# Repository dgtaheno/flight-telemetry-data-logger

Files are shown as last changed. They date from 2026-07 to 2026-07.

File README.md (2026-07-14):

# 🚀 Flight Telemetry & Data Logger

> ESP32-based flight computer featuring GPS telemetry, barometric altitude measurement, runtime diagnostics, health monitoring and fault-tolerant flight data logging.

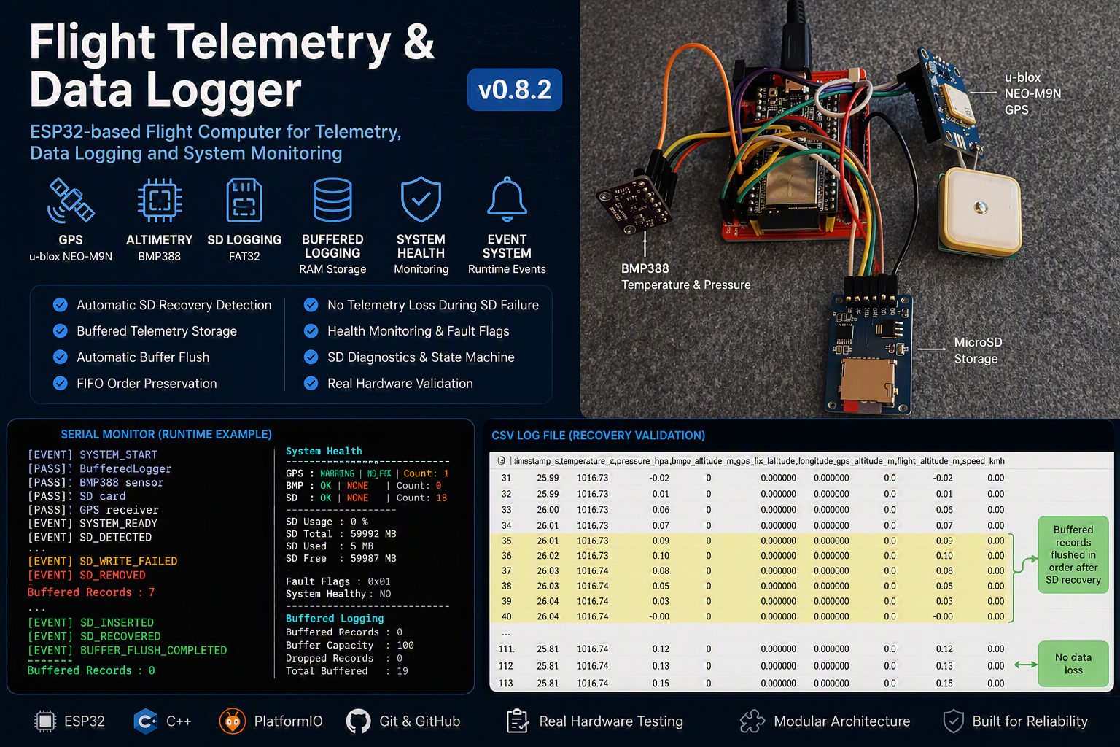
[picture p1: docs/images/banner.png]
Project Banner









---

# Overview

Flight Telemetry & Data Logger is a modular ESP32-based flight computer designed for telemetry acquisition, altitude estimation and reliable flight data recording.

The project combines:

- GPS positioning and navigation
- Barometric altitude measurement
- Flight altitude estimation
- CSV data logging
- Runtime health monitoring
- Event-driven diagnostics
- SD card recovery detection
- Buffered telemetry storage
- Automatic buffer flushing
- FIFO-preserved data recovery

All features documented in this repository have been validated on real hardware.

---

# Hardware

The current prototype uses commercial off-the-shelf modules validated during development.

## ESP32 DevKitC V4

Main controller responsible for:

- Sensor acquisition
- Telemetry processing
- Data logging
- Runtime diagnostics
- Health monitoring
- Event management

---

## BMP388 Barometric Sensor

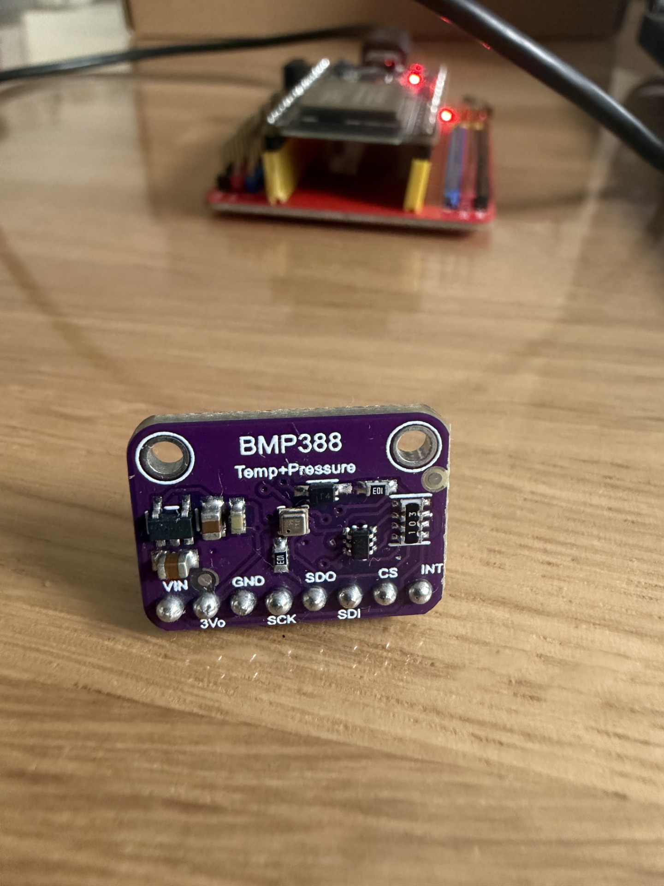
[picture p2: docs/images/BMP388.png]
BMP388


Provides:

- Pressure measurement
- Temperature measurement
- Relative altitude estimation

Configuration:

```text
Interface : I²C

SDA : GPIO21
SCL : GPIO22

Power : 3.3V

CS  : NC
SDO : NC
INT : NC
```

---

## u-blox NEO-M9N GPS Receiver

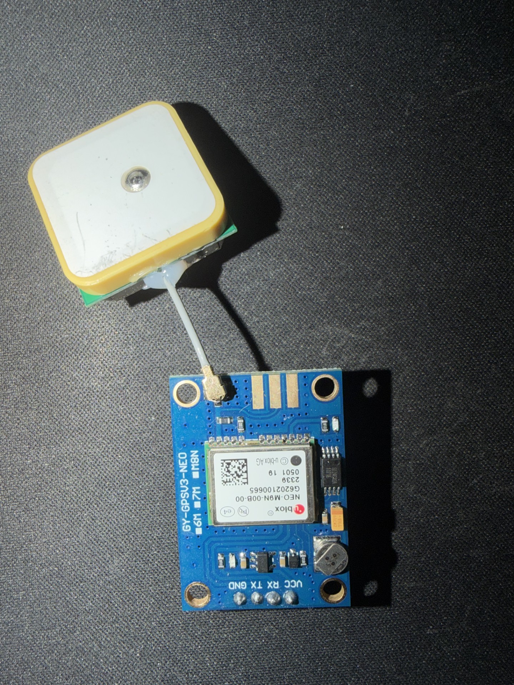
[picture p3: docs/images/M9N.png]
NEO-M9N


Provides:

- GPS position
- GPS altitude
- UTC time
- Ground speed

Configuration:

```text
Interface : UART2

TX : GPIO16
RX : GPIO17

Power : 5V
```

---

## MicroSD Storage Module

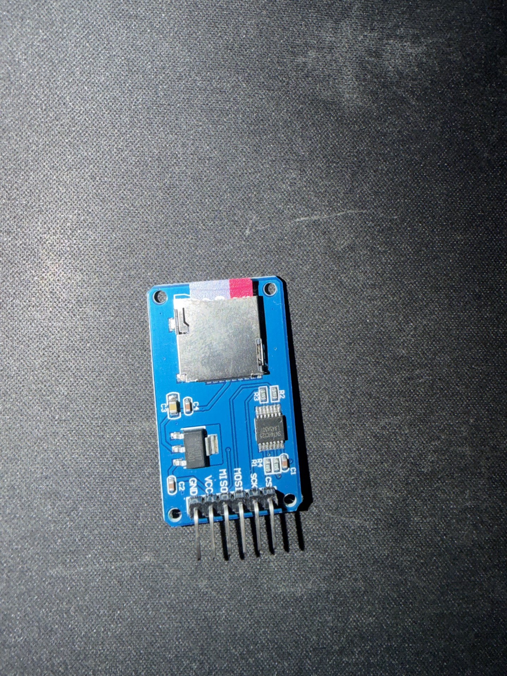
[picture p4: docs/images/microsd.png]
MicroSD


Used for:

- Flight log storage
- Telemetry recording
- Buffered recovery validation

Configuration:

```text
Interface : SPI

CS   : GPIO5
SCK  : GPIO18
MISO : GPIO19
MOSI : GPIO23

Power : 5V
```

---

# Wiring Diagram

The prototype hardware configuration is documented using KiCad and reflects the validated hardware setup.

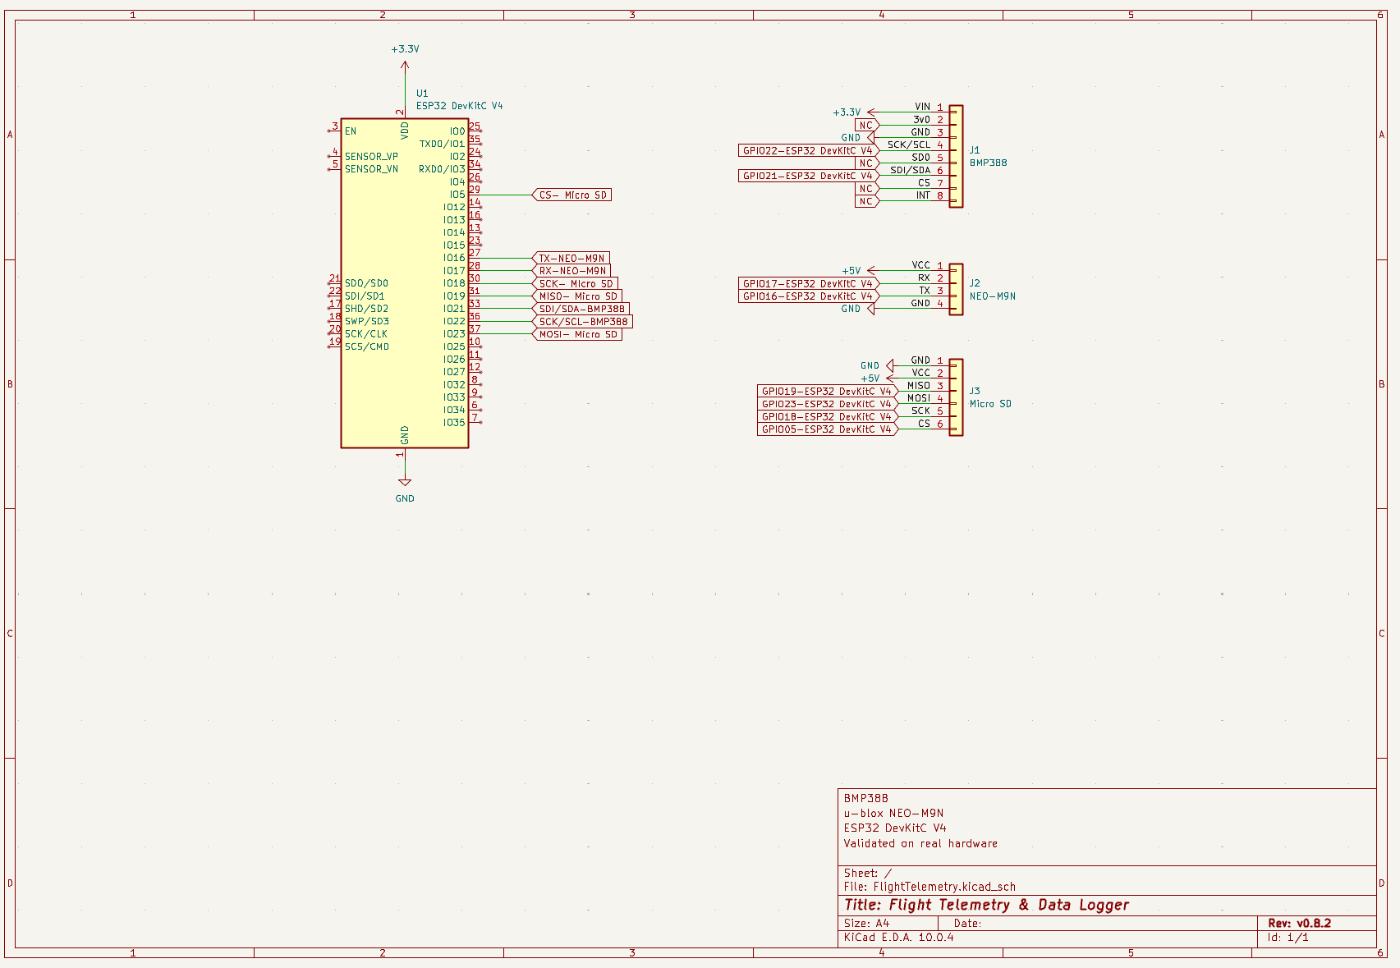
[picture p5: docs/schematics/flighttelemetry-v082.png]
Wiring Diagram


---

# System Architecture

```text
ESP32 DevKitC V4
│
├── BMP388Sensor
│
├── GPSSensor
│
├── SDLogger
│
├── BufferedLogger
│
├── SystemHealth
│
├── SystemEvents
│
└── Flight Logger
```

---

# Features

## Telemetry

✅ GPS Position

✅ GPS Altitude

✅ Ground Speed

✅ UTC Time Acquisition

✅ GPS Timestamp Generation

---

## Altitude System

✅ BMP388 Pressure Measurement

✅ BMP388 Temperature Measurement

✅ Relative Altitude Calculation

✅ Flight Altitude Estimation

✅ GPS Speed Deadband Filtering

---

## Logging

✅ Automatic CSV Logging

✅ FAT32 Support

✅ GPS-Based Filenames

✅ Fallback Filenames

✅ Session-Based Recording

✅ Buffered Logging

✅ Automatic Buffer Flush

✅ FIFO Order Preservation

✅ Automatic Recovery After SD Reinsertion

---

## Reliability

✅ Power-On Self Test (POST)

✅ Runtime Health Monitoring

✅ Fault Flags

✅ Error Counters

✅ Runtime Event System

✅ SD Diagnostics

✅ SD State Machine

✅ SD Removal Detection

✅ SD Recovery Detection

✅ Fault-Tolerant Logging

✅ No Telemetry Loss During SD Recovery

---

# Runtime Event System

Supported events:

```text
SYSTEM_START
SYSTEM_READY

GPS_DETECTED
GPS_LOST

GPS_FIX_ACQUIRED
GPS_FIX_LOST

SD_DETECTED

SD_WRITE_FAILED
SD_REMOVED
SD_INSERTED
SD_RECOVERED

BUFFER_FLUSH_COMPLETED
```

Example:

```text
[EVENT] SD_WRITE_FAILED
[EVENT] SD_REMOVED

...

[EVENT] SD_INSERTED
[EVENT] SD_RECOVERED
[EVENT] BUFFER_FLUSH_COMPLETED
```

---

# Flight Altitude Model

The project combines two independent altitude sources.

```text
Flight Altitude

=
GPS Reference Altitude
+
BMP388 Relative Altitude
```

Example:

```text
Takeoff Altitude : 123.4 m

Climb            : +150.0 m

Flight Altitude  : 273.4 m
```

---

# Flight Logging

## File Naming

When GPS FIX is available:

```text
flight_YYYY-MM-DD_HH-MM-SS.csv
```

Example:

```text
flight_2026-07-11_23-01-48.csv
```

Fallback:

```text
flight_boot_001.csv
```

---

## CSV Format

```csv
timestamp_s,
temperature_c,
pressure_hpa,
bmp_altitude_m,
gps_fix,
latitude,
longitude,
gps_altitude_m,
flight_altitude_m,
speed_kmh
```

---

# Validation Status

Validated on real hardware:

✅ POST Validation

✅ Startup without GPS

✅ Startup without BMP388

✅ Startup without SD

✅ Runtime GPS Detection

✅ Runtime GPS Loss Detection

✅ GPS Detection Timeout

✅ GPS Stale Data Timeout

✅ GPS Fix Timeout

✅ GPS Speed Deadband

✅ SD Diagnostics

✅ SD State Machine

✅ SD Write Failure Detection

✅ SD Removal Detection

✅ SD Recovery Detection

✅ Recovery Statistics

✅ Fault Flags

✅ Error Counters

✅ Health Monitoring

✅ Buffered Logging

✅ Automatic Buffer Flush

✅ FIFO Recovery Validation

✅ No Telemetry Loss During SD Failure

---

# Buffered Logging Validation

Scenario:

```text
SD card removed during active logging

↓

Telemetry stored in RAM buffer

↓

SD card reinserted

↓

Automatic flush executed

↓

Buffered records written to CSV

↓

Buffer returns to zero
```

Validated:

```text
✅ Automatic SD Recovery

✅ Automatic Buffer Flush

✅ FIFO Order Preservation

✅ No Telemetry Loss
```

---

# Current Status

Release:

```text
v0.8.2
```

Completed:

```text
ESP32 Bring-Up

BMP388 Integration

GPS Integration

TinyGPSPlus Integration

SD Logging

Power-On Self Test

Health Monitoring

Runtime Event System

Fault Flags

Error Counters

SD Diagnostics

SD State Machine

GPS Runtime Detection

GPS Startup Detection

SD Recovery Detection

Buffered Logging

Automatic Buffer Flush

FIFO Recovery Validation
```

---

# Planned Features

```text
Flight Analytics

LoRa Telemetry

Ground Station Dashboard

INA219 Power Monitoring

Battery Telemetry

FreeRTOS Architecture
```

---

# Roadmap

## v0.9.x

```text
Flight Analytics

Maximum Altitude
Maximum Speed
Flight Duration
Vertical Velocity
```

---

## v1.0

```text
LoRa Telemetry

Ground Station

Real-Time Data Transmission
```

---

## Future

```text
INA219 Power Monitoring

FreeRTOS Migration

Task Separation

Telemetry Queues
```

---

# Project Structure

```text
flight-telemetry-data-logger
│
├── include
│
├── lib
│   ├── BMP388Sensor
│   ├── GPSSensor
│   ├── SDLogger
│   ├── BufferedLogger
│   ├── SystemHealth
│   └── SystemEvents
│
├── src
│
├── docs
│   ├── images
│   │   ├── banner.png
│   │   ├── BMP388.png
│   │   ├── M9N.png
│   │   └── microsd.png
│   │
│   ├── schematics
│   │   └── flighttelemetry-v082.png
│   │
│   └── TestReport_Sprint8.md
│
└── README.md
```

---

# Privacy

All coordinates, timestamps and telemetry samples shown in this repository are synthetic examples or validation data and should not be considered representative of real locations.

---

# License

MIT License

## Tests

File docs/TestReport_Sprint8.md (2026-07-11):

# Test Report – Sprint 8

## Project

Flight Telemetry & Data Logger

Platform:

```text
ESP32 DevKitC V4
BMP388
u-blox NEO-M9N
MicroSD Storage
```

Date:

```text
2026-07-11
```

---

# Objective

Validate the Health Monitoring subsystem, SD diagnostics, Runtime Event System, SD State Machine and configuration parameters under real hardware conditions.

---

# Test Environment

## Hardware

```text
ESP32 DevKitC V4
BMP388
u-blox NEO-M9N
MicroSD Card
```

## Firmware

```text
Sprint 8.1B
```

Validated Modules:

```text
BMP388Sensor
GPSSensor
SDLogger
SystemHealth
SystemEvents
```

---

# Summary

| Test ID | Description | Result |
|---|---|---|
| T01 | Normal Startup | PASS |
| T02 | BMP388 Detection | PASS |
| T03 | GPS Detection | PASS |
| T04 | SD Detection | PASS |
| T05 | Flight Log Creation | PASS |
| T06 | GPS Timestamped Filename | PASS |
| T07 | Runtime Health Monitoring | PASS |
| T08 | Fault Flags | PASS |
| T09 | SD Diagnostics | PASS |
| T10 | SD Write Failure Detection | PASS |
| T11 | SD Removal Detection | PASS |
| T12 | SD Recovery Detection | PASS |
| T13 | SD State Machine | PASS |
| T14 | Recovery Statistics | PASS |
| T15 | GPS Speed Deadband | PASS |
| T20 | Startup without SD | PASS |
| T21 | Startup without GPS Power | PASS |
| T22 | Startup without BMP388 | PASS |
| T50 | CSV Recovery Validation | PASS |

---

# Test Cases

---

## T01 – Normal Startup

### Procedure

```text
Power cycle system
Allow POST to execute
```

### Expected

```text
All modules pass self-test
System READY
```

### Result

```text
PASS
```

Observed:

```text
[PASS] BMP388 sensor
[PASS] SD card
[PASS] GPS receiver

System READY
```

---

## T02 – BMP388 Detection

### Procedure

```text
Run POST
```

### Expected

```text
BMP388 detected
```

### Result

```text
PASS
```

Observed:

```text
[PASS] BMP388 sensor
```

---

## T03 – GPS Detection

### Procedure

```text
Run POST
```

### Expected

```text
GPS receiver detected
```

### Result

```text
PASS
```

Observed:

```text
[PASS] GPS receiver
```

---

## T04 – SD Detection

### Procedure

```text
Run POST
```

### Expected

```text
SD card detected
```

### Result

```text
PASS
```

Observed:

```text
[PASS] SD card
```

---

## T05 – Flight Log Creation

### Procedure

```text
Start system with GPS FIX
```

### Expected

```text
Flight log created
```

### Result

```text
PASS
```

Observed:

```text
flight_YYYY-MM-DD_HH-MM-SS.csv
```

Example:

```text
flight_2026-07-11_23-01-48.csv
```

---

## T06 – GPS Timestamped Filename

### Procedure

```text
Acquire GPS FIX
Create flight log
```

### Expected

```text
Filename contains GPS date/time
```

### Result

```text
PASS
```

---

## T07 – Runtime Health Monitoring

### Procedure

```text
Operate system normally
```

### Expected

```text
All modules report OK
```

### Result

```text
PASS
```

Observed:

```text
GPS : OK
BMP : OK
SD  : OK

System Healthy : YES
```

---

## T08 – Fault Flags

### Procedure

```text
Run system normally
Remove SD card
```

### Expected

```text
SD fault flag set
```

### Result

```text
PASS
```

Observed:

```text
Fault Flags : 0x04
```

---

## T09 – SD Diagnostics

### Procedure

```text
Observe storage monitoring
```

### Expected

```text
Capacity values displayed
```

### Result

```text
PASS
```

Observed:

```text
SD Total
SD Used
SD Free
SD Usage %
```

---

# Runtime Event System

---

## T10 – SD Write Failure Detection

### Procedure

```text
Remove SD card during operation
```

### Expected

```text
SD write failure event generated
```

### Result

```text
PASS
```

Observed:

```text
[EVENT] SD_WRITE_FAILED
```

---

## T11 – SD Removal Detection

### Procedure

```text
Remove SD card
Leave removed for >30 seconds
```

### Expected

```text
SD_REMOVED event generated
```

### Result

```text
PASS
```

Observed:

```text
[EVENT] SD_REMOVED
```

---

## T12 – SD Recovery Detection

### Procedure

```text
Reinsert SD card
```

### Expected

```text
SD recovery event generated
```

### Result

```text
PASS
```

Observed:

```text
[EVENT] SD_INSERTED

[EVENT] SD_RECOVERED
```

---

## T13 – SD State Machine

### Procedure

```text
Remove SD
Wait
Reinsert SD
```

### Expected

```text
OK
↓
WRITE_FAILED
↓
REMOVED
↓
RECOVERED
↓
OK
```

### Result

```text
PASS
```

Observed:

```text
State : WRITE_FAILED

State : REMOVED

State : OK
```

---

## T14 – Recovery Statistics

### Procedure

```text
Perform SD removal and reinsertion
```

### Expected

```text
Counters updated
```

### Result

```text
PASS
```

Observed:

```text
Removal Count  : 1
Recovery Count : 1
Write Failures : 6
```

---

## T15 – GPS Speed Deadband

### Procedure

```text
Leave system stationary
```

### Expected

```text
Speed = 0.00 km/h
```

### Result

```text
PASS
```

Observed:

```text
Speed : 0.00 km/h
```

---

# Startup Validation Tests

---

## T20 – Startup without SD

### Procedure

```text
Remove SD card
Power cycle system
```

### Expected

```text
SD card not detected
```

### Result

```text
PASS
```

Observed:

```text
[FAIL] SD card not detected

Please check:
 - microSD card is inserted
 - SD module wiring
 - SD module power supply (5V)
 - SD card format (FAT32)
```

### Conclusion

```text
POST correctly detects SD absence.
```

---

## T21 – Startup without GPS Power

### Procedure

```text
Disconnect GPS VCC
Power cycle system
```

### Expected

```text
GPS receiver not detected

GPS Detected = NO
```

### Result

```text
PASS
```

Observed:

```text
[WARN] GPS receiver not detected

[WARN] GPS fix unavailable

GPS Detected : NO

GPS Fix      : NO

Flight log created

Fallback filename used
```

### Conclusion

```text
GPS absence correctly detected.

System remains operational
using degraded mode.
```

---

## T22 – Startup without BMP388

### Procedure

```text
Disconnect BMP388
Power cycle system
```

### Expected

```text
BMP388 self-test fails
```

### Result

```text
PASS
```

Observed:

```text
[Wire.cpp:499] requestFrom(): i2cWriteReadNonStop returned Error 263

[FAIL] BMP388 self-test failed
```

### Conclusion

```text
BMP388 absence correctly detected.

I2C communication loss correctly triggers self-test failure.
```

---

# Recovery Validation Tests

---

## T50 – CSV Recovery Validation

### Procedure

```text
Create log

Remove SD card

Wait approximately 40 seconds

Reinsert SD card

Continue logging

Open CSV file
```

### Expected

```text
Logging resumes after SD recovery.
```

### Result

```text
PASS
```

### Observed

```text
Timestamp sequence:

24

...

65

...

106
```

### Conclusion

```text
CSV logging resumes correctly after SD recovery.

Records generated while SD storage
was unavailable are lost.

Buffered logging is required
to prevent data loss.
```

---

# Configuration Validation

The following configuration parameters defined in Config.h have been validated using real hardware tests.

---

## C01 – GPS Detection Timeout

### Parameter

```text
GPS_DETECTION_TIMEOUT_MS
```

### Validation

```text
Startup with GPS disconnected.
```

### Result

```text
PASS
```

Observed:

```text
[WARN] GPS receiver not detected

GPS Detected : NO

GPS Fix      : NO
```

---

## C02 – GPS Stale Data Timeout

### Parameter

```text
GPS_STALE_DATA_TIMEOUT_MS
```

### Validation

```text
Disconnect GPS during operation.
```

### Result

```text
PASS
```

Observed:

```text
GPS Detected : NO

GPS Fix      : NO

GPS : WARNING

Error : NO_DATA
```

---

## C03 – GPS Fix Timeout

### Parameter

```text
GPS_FIX_TIMEOUT_SECONDS
```

### Validation

```text
Startup without GPS availability.
```

### Result

```text
PASS
```

Observed:

```text
[WARN] GPS fix unavailable

[INFO] Using fallback filename

flight_boot_014.csv
```

---

## C04 – SD Removal Threshold

### Parameter

```text
SD_REMOVAL_FAILURE_THRESHOLD
```

### Validation

```text
Remove SD card during operation.
```

### Result

```text
PASS
```

Observed:

```text
[EVENT] SD_WRITE_FAILED

[EVENT] SD_REMOVED
```

---

## C05 – GPS Speed Deadband

### Parameter

```text
GPS_SPEED_DEADBAND_KMH
```

### Validation

```text
System stationary.
```

### Result

```text
PASS
```

Observed:

```text
Speed : 0.00 km/h
```

---

# Known Issues

```text
No known open issues.
```

---

# Conclusions

Sprint 8.0 objectives successfully validated.

Validated in real hardware:

```text
POST
Health Monitoring
Fault Flags
SD Diagnostics
Runtime Event System
SD State Machine
SD Write Failure Detection
SD Removal Detection
SD Recovery Detection
Recovery Statistics
GPS Runtime Loss Detection
GPS Startup Detection
CSV Recovery Validation
```

Configuration validation completed:

```text
GPS Detection Timeout
GPS Stale Data Timeout
GPS Fix Timeout
SD Removal Threshold
GPS Speed Deadband
```

Overall Result:

```text
SPRINT 8.0 PASSED

SPRINT 8.1A PASSED

SPRINT 8.1B PASSED

NO OPEN ISSUES
```

---

# Next Sprint

```text
Sprint 8.2

- Buffered Logging
- Circular Buffer
- Pending Records Counter
- Automatic SD Flush
- Automatic SD Recovery Storage
```

Future:

```text
Sprint 9

- LoRa Telemetry
- Ground Station Integration

Sprint 10

- INA219 Power Monitoring

Sprint 11

- Flight Analytics

Sprint 12

- FreeRTOS Architecture
```

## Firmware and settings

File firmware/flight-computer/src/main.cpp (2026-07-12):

#include <Arduino.h>
#include <math.h>

#include "Config.h"
#include "BMP388Sensor.h"
#include "SDLogger.h"
#include "GPSSensor.h"
#include "SystemHealth.h"
#include "SystemEvents.h"
#include "BufferedLogger.h"

// --------------------------------------------------
// System Modules
// --------------------------------------------------

BMP388Sensor bmp;
SDLogger logger;
GPSSensor gps;
SystemHealth health;
SystemEvents events;
BufferedLogger telemetryBuffer;

// --------------------------------------------------
// Timing
// --------------------------------------------------

unsigned long lastLog = 0;
unsigned long lastHealthPrint = 0;

// --------------------------------------------------
// GPS Altitude Reference
// --------------------------------------------------

bool gpsReferenceCaptured = false;
float gpsReferenceAltitude = 0.0f;

// --------------------------------------------------
// GPS Health State Tracking
// --------------------------------------------------

bool gpsWarningActive = false;
GpsErrorCode activeGpsWarning = GPS_ERROR_NONE;

// --------------------------------------------------
// Helper: Write Telemetry Record to SD
// --------------------------------------------------

bool writeTelemetryRecordToSd(
    const TelemetryRecord& record)
{
    return logger.writeData(
        record.timestamp,
        record.temperature,
        record.pressure,
        record.bmpAltitude,
        record.gpsFix,
        record.latitude,
        record.longitude,
        record.gpsAltitude,
        record.flightAltitude,
        record.speed);
}

// --------------------------------------------------
// Helper: Flush Buffered Telemetry Records
// --------------------------------------------------

bool flushBufferedRecords()
{
    if (telemetryBuffer.isEmpty())
    {
        return true;
    }

    events.logEvent(
        EVENT_BUFFER_FLUSH_STARTED);

    while (!telemetryBuffer.isEmpty())
    {
        TelemetryRecord pendingRecord;

        // IMPORTANT:
        // Use peek() first to preserve FIFO order.
        // Only remove the record from the buffer
        // after it has been written successfully.
        if (!telemetryBuffer.peek(pendingRecord))
        {
            return false;
        }

        bool writeOk =
            writeTelemetryRecordToSd(
                pendingRecord);

        events.updateSdState(
            true,
            writeOk,
            logger.isStorageFull());

        if (!writeOk)
        {
            return false;
        }

        TelemetryRecord discardedRecord;

        telemetryBuffer.pop(
            discardedRecord);
    }

    events.logEvent(
        EVENT_BUFFER_FLUSH_COMPLETED);

    return true;
}

// --------------------------------------------------
// Helper: Update SD Health Information
// --------------------------------------------------

void updateSdHealth()
{
    uint64_t totalBytes = logger.getTotalBytes();
    uint64_t usedBytes = logger.getUsedBytes();

    if (events.isSdRemoved())
    {
        health.reportSdFailure(
            SD_ERROR_CARD_REMOVED);

        return;
    }

    if (totalBytes == 0)
    {
        health.reportSdFailure(
            SD_ERROR_NOT_INITIALIZED);

        return;
    }

    health.updateSdStorage(
        totalBytes,
        usedBytes);
}

// --------------------------------------------------
// Helper: Report GPS Health Without Counter Spam
// --------------------------------------------------

void reportGpsHealth(
    bool gpsDetected,
    bool gpsFix)
{
    if (!gpsDetected)
    {
        if (!gpsWarningActive ||
            activeGpsWarning != GPS_ERROR_NO_DATA)
        {
            health.reportGpsWarning(
                GPS_ERROR_NO_DATA);

            gpsWarningActive = true;
            activeGpsWarning = GPS_ERROR_NO_DATA;
        }

        return;
    }

    if (!gpsFix)
    {
        if (!gpsWarningActive ||
            activeGpsWarning != GPS_ERROR_NO_FIX)
        {
            health.reportGpsWarning(
                GPS_ERROR_NO_FIX);

            gpsWarningActive = true;
            activeGpsWarning = GPS_ERROR_NO_FIX;
        }

        return;
    }

    health.reportGpsOk();

    gpsWarningActive = false;
    activeGpsWarning = GPS_ERROR_NONE;
}

// --------------------------------------------------
// Helper: Print System Health Periodically
// --------------------------------------------------

void printHealthIfNeeded()
{
#if PRINT_HEALTH_TO_SERIAL

    if (millis() - lastHealthPrint >= HEALTH_PRINT_INTERVAL_MS)
    {
        lastHealthPrint = millis();

        health.printStatus();

        events.printSdState();

        Serial.println();
        Serial.println("Buffered Logging");
        Serial.println("--------------------------------");

        Serial.print("Buffered Records : ");
        Serial.println(telemetryBuffer.size());

        Serial.print("Buffer Capacity  : ");
        Serial.println(telemetryBuffer.capacity());

        Serial.print("Buffer Free      : ");
        Serial.println(telemetryBuffer.freeSpace());

        Serial.print("Dropped Records  : ");
        Serial.println(telemetryBuffer.getDroppedRecords());

        Serial.print("Total Buffered   : ");
        Serial.println(telemetryBuffer.getTotalBuffered());

        Serial.println("--------------------------------");
        Serial.println();
    }

#endif
}

// --------------------------------------------------
// Setup
// --------------------------------------------------

void setup()
{
    Serial.begin(115200);

    health.reset();

    events.begin();

    events.logEvent(
        EVENT_SYSTEM_START);

    Serial.println();
    Serial.println("================================");
    Serial.println(SYSTEM_NAME);
    Serial.println("================================");
    Serial.println();

    Serial.println("Running Power-On Self Test (POST)...");
    Serial.println();

    // --------------------------------------------------
    // BufferedLogger Self-Test
    // --------------------------------------------------

    Serial.println("BufferedLogger Self-Test");

    TelemetryRecord test = {};
    test.timestamp = 123;

    if (!telemetryBuffer.push(test))
    {
        Serial.println("[FAIL] BufferedLogger push");
    }
    else
    {
        TelemetryRecord out = {};

        if (!telemetryBuffer.pop(out))
        {
            Serial.println("[FAIL] BufferedLogger pop");
        }
        else if (out.timestamp != 123)
        {
            Serial.println("[FAIL] BufferedLogger FIFO");
        }
        else
        {
            Serial.println("[PASS] BufferedLogger");
        }
    }

    // --------------------------------------------------
    // BMP388
    // --------------------------------------------------

    if (!bmp.begin())
    {
        health.reportBmpFailure(
            BMP_ERROR_READ_FAILED);

        Serial.println("[FAIL] BMP388 sensor not detected");

#if HALT_ON_BMP388_FAIL
        while (1)
        {
            delay(1000);
        }
#endif
    }

    if (!bmp.selfTest())
    {
        health.reportBmpFailure(
            BMP_ERROR_INVALID_DATA);

        Serial.println("[FAIL] BMP388 self-test failed");

#if HALT_ON_BMP388_FAIL
        while (1)
        {
            delay(1000);
        }
#endif
    }

    health.reportBmpOk();

    Serial.println("[PASS] BMP388 sensor");

    // --------------------------------------------------
    // SD Card
    // --------------------------------------------------

    if (!logger.begin())
    {
        health.reportSdFailure(
            SD_ERROR_NOT_INITIALIZED);

        Serial.println("[FAIL] SD card not detected");
        Serial.println();
        Serial.println("Please check:");
        Serial.println(" - microSD card is inserted");
        Serial.println(" - SD module wiring");
        Serial.println(" - SD module power supply (5V)");
        Serial.println(" - SD card format (FAT32)");

#if HALT_ON_SD_FAIL
        while (1)
        {
            delay(1000);
        }
#endif
    }

    if (!logger.selfTest())
    {
        health.reportSdFailure(
            SD_ERROR_SELFTEST_FAILED);

        Serial.println("[FAIL] SD card self-test failed");

#if HALT_ON_SD_FAIL
        while (1)
        {
            delay(1000);
        }
#endif
    }

    health.reportSdOk();
    updateSdHealth();

    Serial.println("[PASS] SD card");

#if GPS_ENABLED

    // --------------------------------------------------
    // GPS
    // --------------------------------------------------

    gps.begin();

    if (!gps.selfTest())
    {
        health.reportGpsWarning(
            GPS_ERROR_NO_DATA);

        gpsWarningActive = true;
        activeGpsWarning = GPS_ERROR_NO_DATA;

        Serial.println("[WARN] GPS receiver not detected");
    }
    else
    {
        health.reportGpsOk();

        gpsWarningActive = false;
        activeGpsWarning = GPS_ERROR_NONE;

        Serial.println("[PASS] GPS receiver");
    }

#endif

#if GPS_ENABLED

    // --------------------------------------------------
    // Wait for GPS Fix
    // --------------------------------------------------

    unsigned long gpsStart = millis();

    while ((millis() - gpsStart) <
           (GPS_FIX_TIMEOUT_SECONDS * 1000UL))
    {
        gps.update();

        if (gps.hasFix())
        {
            break;
        }

        delay(50);
    }

    reportGpsHealth(
        gps.isDetected(),
        gps.hasFix());

#endif

    // --------------------------------------------------
    // Create Flight Log
    // --------------------------------------------------

#if GPS_ENABLED

    if (gps.hasFix())
    {
        Serial.println("[INFO] Creating GPS timestamped log file");

        if (!logger.createLogFile(
                gps.getLocalDate(),
                gps.getLocalTime()))
        {
            health.reportSdFailure(
                SD_ERROR_FILE_CREATION_FAILED);

            Serial.println("[FAIL] Flight log creation failed");

#if HALT_ON_SD_FAIL
            while (1)
            {
                delay(1000);
            }
#endif
        }
    }
    else
    {
        Serial.println("[WARN] GPS fix unavailable");
        Serial.println("[INFO] Using fallback filename");

        if (!logger.createLogFile())
        {
            health.reportSdFailure(
                SD_ERROR_FILE_CREATION_FAILED);

            Serial.println("[FAIL] Flight log creation failed");

#if HALT_ON_SD_FAIL
            while (1)
            {
                delay(1000);
            }
#endif
        }
    }

#else

    if (!logger.createLogFile())
    {
        health.reportSdFailure(
            SD_ERROR_FILE_CREATION_FAILED);

        Serial.println("[FAIL] Flight log creation failed");

#if HALT_ON_SD_FAIL
        while (1)
        {
            delay(1000);
        }
#endif
    }

#endif

    health.reportSdOk();
    updateSdHealth();

    Serial.print("[PASS] Flight log: ");
    Serial.println(logger.getLogFileName());

    Serial.println();
    Serial.println("All systems passed");
    Serial.println("System READY");
    Serial.println();

    events.logEvent(
        EVENT_SYSTEM_READY);

    health.printStatus();
}

// --------------------------------------------------
// Main Loop
// --------------------------------------------------

void loop()
{
#if GPS_ENABLED
    gps.update();
#endif

    if (millis() - lastLog >= LOG_INTERVAL_MS)
    {
        lastLog = millis();

        // --------------------------------------------------
        // BMP388 Update
        // --------------------------------------------------

        if (!bmp.update())
        {
            health.reportBmpFailure(
                BMP_ERROR_READ_FAILED);

            events.updateBmpState(
                false);

            Serial.println("[WARN] BMP388 read error");

            printHealthIfNeeded();

            return;
        }

        health.reportBmpOk();

        events.updateBmpState(
            true);

        float temperature = bmp.getTemperature();
        float pressure = bmp.getPressure();
        float bmpAltitude = bmp.getRelativeAltitude();

#if GPS_ENABLED

        // --------------------------------------------------
        // GPS Update
        // --------------------------------------------------

        bool gpsDetected = gps.isDetected();
        bool gpsFix = gps.hasFix();

        events.updateGpsState(
            gpsDetected,
            gpsFix);

        reportGpsHealth(
            gpsDetected,
            gpsFix);

        double latitude = gps.getLatitude();
        double longitude = gps.getLongitude();

        float gpsAltitude = gps.getAltitude();
        float gpsSpeed = gps.getSpeed();

        // --------------------------------------------------
        // GPS Speed Deadband
        // --------------------------------------------------

        if (fabs(gpsSpeed) < GPS_SPEED_DEADBAND_KMH)
        {
            gpsSpeed = 0.0f;
        }

#else

        bool gpsDetected = false;
        bool gpsFix = false;

        double latitude = 0.0;
        double longitude = 0.0;

        float gpsAltitude = 0.0f;
        float gpsSpeed = 0.0f;

#endif

        // --------------------------------------------------
        // Capture GPS Reference Altitude
        // --------------------------------------------------

        if (gpsFix && !gpsReferenceCaptured)
        {
            gpsReferenceAltitude = gpsAltitude;
            gpsReferenceCaptured = true;

            Serial.print("[INFO] GPS reference altitude captured: ");
            Serial.print(gpsReferenceAltitude, 1);
            Serial.println(" m");
        }

        // --------------------------------------------------
        // Flight Altitude
        // --------------------------------------------------

        float flightAltitude = 0.0f;

        if (gpsReferenceCaptured)
        {
            flightAltitude =
                gpsReferenceAltitude +
                bmpAltitude;
        }
        else
        {
            flightAltitude = gpsAltitude;
        }

        // --------------------------------------------------
        // Create Telemetry Record
        // --------------------------------------------------

        TelemetryRecord record = {};

        record.timestamp = millis() / 1000;

        record.temperature = temperature;
        record.pressure = pressure;
        record.bmpAltitude = bmpAltitude;

        record.gpsFix = gpsFix;

        record.latitude = latitude;
        record.longitude = longitude;

        record.gpsAltitude = gpsAltitude;
        record.flightAltitude = flightAltitude;

        record.speed = gpsSpeed;

        // --------------------------------------------------
        // Store Telemetry
        // --------------------------------------------------

        bool writeOk = false;

        if (!telemetryBuffer.isEmpty())
        {
            if (!telemetryBuffer.push(record))
            {
                events.logEvent(
                    EVENT_BUFFER_OVERFLOW);
            }

            writeOk =
                flushBufferedRecords();
        }
        else
        {
            writeOk =
                writeTelemetryRecordToSd(record);

            events.updateSdState(
                true,
                writeOk,
                logger.isStorageFull());

            if (!writeOk)
            {
                if (!telemetryBuffer.push(record))
                {
                    events.logEvent(
                        EVENT_BUFFER_OVERFLOW);
                }
                else
                {
                    events.logEvent(
                        EVENT_BUFFER_RECORD_STORED);
                }
            }
        }

        // --------------------------------------------------
        // Health Reporting
        // --------------------------------------------------

        if (writeOk)
        {
            health.reportSdOk();
        }
        else
        {
            if (events.isSdRemoved())
            {
                health.reportSdFailure(
                    SD_ERROR_CARD_REMOVED);
            }
            else if (logger.isStorageFull())
            {
                health.reportSdFailure(
                    SD_ERROR_CARD_FULL);
            }
            else
            {
                health.reportSdFailure(
                    SD_ERROR_WRITE_FAILED);
            }
        }

        updateSdHealth();

#if PRINT_TELEMETRY_TO_SERIAL

        // --------------------------------------------------
        // Console Output
        // --------------------------------------------------

        Serial.println("--------------------------------");

        Serial.print("Temperature : ");
        Serial.print(temperature, 2);
        Serial.println(" C");

        Serial.print("Pressure    : ");
        Serial.print(pressure, 2);
        Serial.println(" hPa");

        Serial.print("BMP Alt     : ");
        Serial.print(bmpAltitude, 2);
        Serial.println(" m");

#if GPS_ENABLED

        Serial.println();

        Serial.print("GPS Detected: ");
        Serial.println(gpsDetected ? "YES" : "NO");

        Serial.print("GPS Fix     : ");
        Serial.println(gpsFix ? "YES" : "NO");

        if (gpsFix)
        {
            Serial.print("Latitude    : ");
            Serial.println(latitude, 6);

            Serial.print("Longitude   : ");
            Serial.println(longitude, 6);

            Serial.print("GPS Alt     : ");
            Serial.print(gpsAltitude, 1);
            Serial.println(" m");

            Serial.print("Flight Alt  : ");
            Serial.print(flightAltitude, 2);
            Serial.println(" m");

            Serial.print("Speed       : ");
            Serial.print(gpsSpeed, 2);
            Serial.println(" km/h");

            Serial.print("UTC Date    : ");
            Serial.println(gps.getUtcDate());

            Serial.print("UTC Time    : ");
            Serial.println(gps.getUtcTime());

            Serial.print("Local Time  : ");
            Serial.println(gps.getLocalTime());
        }

#endif

        Serial.println("--------------------------------");
        Serial.println();

#endif

        printHealthIfNeeded();
    }
}

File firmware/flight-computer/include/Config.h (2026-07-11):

#pragma once

// =====================================================
// System Information
// =====================================================

#define SYSTEM_NAME                    "Flight Telemetry & Data Logger"
#define SYSTEM_VERSION                 "0.8.0"

// =====================================================
// Installed Modules
// =====================================================

#define BMP388_ENABLED                 true
#define GPS_ENABLED                    true
#define SD_LOGGER_ENABLED              true

#define SYSTEM_HEALTH_ENABLED          true
#define EVENT_LOGGING_ENABLED          true
#define BUFFERED_LOGGING_ENABLED       true

#define LORA_ENABLED                   false
#define INA219_ENABLED                 false

// =====================================================
// GPS Configuration
// =====================================================

#define GPS_UART_BAUDRATE              38400

#define GPS_RX_PIN                     16
#define GPS_TX_PIN                     17

// Local time offset from UTC
#define UTC_OFFSET_HOURS               2

// Ignore GPS speed values below this threshold.
// Helps eliminate GPS noise when the device is stationary.
#define GPS_SPEED_DEADBAND_KMH         3.0f

// Time to wait during startup for GPS FIX before using fallback filename.
#define GPS_FIX_TIMEOUT_SECONDS        30

// =====================================================
// BMP388 Configuration
// =====================================================

#define BMP388_I2C_ADDRESS             0x77

// =====================================================
// SD Card Configuration
// =====================================================

#define SD_CS_PIN                      5

// SD usage monitoring thresholds
#define SD_USAGE_WARNING_PERCENT       80
#define SD_USAGE_CRITICAL_PERCENT      95
#define SD_USAGE_FULL_PERCENT          99

// =====================================================
// Logging Configuration
// =====================================================

#define LOG_INTERVAL_MS                1000

#define CSV_DECIMAL_PLACES             2

// Number of telemetry records stored in RAM if SD writing fails.
// This provides short-term protection against temporary SD write failures.
#define LOG_BUFFER_SIZE                100

// =====================================================
// GPS Logging Configuration
// =====================================================

#define USE_LOCAL_TIME_FOR_LOGS        true

#define FALLBACK_TO_BOOT_FILENAME      true

// =====================================================
// System Health Configuration
// =====================================================

// How often the system health status is printed to Serial.
#define HEALTH_PRINT_INTERVAL_MS       10000

// Timeout thresholds for detecting stale module activity.
#define GPS_DATA_TIMEOUT_MS            5000
#define BMP_DATA_TIMEOUT_MS            3000
#define SD_WRITE_TIMEOUT_MS            5000

// =====================================================
// POST Configuration
// =====================================================

#define HALT_ON_BMP388_FAIL            true
#define HALT_ON_SD_FAIL                true
#define HALT_ON_GPS_FAIL               false

// =====================================================
// Event Logging Configuration
// =====================================================

#define EVENT_LOG_FILE_NAME            "/events.log"

// =====================================================
// Debug Configuration
// =====================================================

#define PRINT_TELEMETRY_TO_SERIAL      true
#define PRINT_HEALTH_TO_SERIAL         true

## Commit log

2026-07-04 Initial ESP32 PlatformIO project
2026-07-04 Add BMP388 relative altitude sensor
2026-07-04 Refactor BMP388 sensor module and altitude calibration
2026-07-09 Improve flight altitude calculation and GPS speed filtering
2026-07-09 Complete Sprint 7: flight altitude and GPS speed filtering
2026-07-12 Sprint 8.2B: buffer telemetry records during SD failure
    [main.cpp]
2026-07-14 Docs: add KiCad schematic project
    [FlightTelemetry.kicad_pcb, FlightTelemetry.kicad_sch]
